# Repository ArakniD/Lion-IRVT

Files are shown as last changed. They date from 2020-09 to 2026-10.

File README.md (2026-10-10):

# Lion-IRVT

An eight-channel bidirectional battery test system (BTS) — charge and discharge,
constant-current and constant-voltage — for testing and characterising
18650-class lithium cells. The workspace file is `18650-Tester-Project.DsnWrk`;
that is what the instrument is for.

The power stage and control card derive from Texas Instruments reference design
**TIDA-010086**, a 10 A battery formation and test design that TI documents as
scalable to eight channels. Here it is built out to all eight, retargeted to the
**TMS320F28379D**, and split across both of its cores. An ESP32 sits on top as
host controller.

| Layer | Device | Job |
|---|---|---|
| Control | F28379D **CPU1** | Eight independent synchronous bidirectional converters. HRPWM, DCL control loops, external SPI ADC (ADS131M08), on-chip ADC, trip handling. |
| Communication | F28379D **CPU2** | I2C target register file for the host, I2C controller for F-RAM and the ADS1119 temperature converters, UART AT console (debug build), CAN telemetry, calibration and slot-state persistence. |
| Supervision | **ESP32** (LOLIN32 v1.0.0) | I2C controller. Owns the test sequence and cell limits, integrates mAh/mWh, records results, drives the eight WS2812B slot LEDs, and exposes BLE GATT, a JSON HTTP API with a setup page, WiFi firmware update, and an ST7789 LCD with a rotary encoder. |

## Configuring the unit — MODE and ENABLE switches

Two 8-way DIP switches on the board set how the unit runs. **MODE** decides
how the eight slots are grouped; **ENABLE** decides how many slots are in
use. Both are read **once, at power-on** — change a switch, then power-cycle.
**Turn on exactly one switch on each.** DIP *n* selects setting *n* − 1.

**MODE — slot grouping**

| MODE DIP | `eSlotMode` | Name | Slot groups | Voltage loop from | What it is for |
|---|---|---|---|---|---|
| **1** | **0** | Independent | 8 groups of 1 | ADS131M08 | **Normal use.** Eight separate cells, each with its own test |
| 2 | 1 | Pairs | 1+2, 3+4, 5+6, 7+8 | ADS131M08 | One cell on two slots in parallel, up to twice the current |
| 3 | 2 | Quads | 1–4, 5–8 | ADS131M08 | One cell on four slots, up to four times the current |
| 4 *(or none)* | 3 | Octet | 1–8 | ADS131M08 | One cell on all eight slots |
| 5 | 4 | Independent, internal ADC | 8 groups of 1 | C2000 12-bit ADC | As MODE DIP 1, with the voltage loop closed on the on-chip ADC |
| 6 | 5 | Pairs, internal ADC | as MODE DIP 2 | C2000 12-bit ADC | As MODE DIP 2, internal ADC |
| 7 | 6 | Loop tuning — plant | one slot | — | Bench only. SFRA sweep of the converter with its loop open |
| 8 | 7 | Loop tuning — closed loop | one slot | — | Bench only. SFRA sweep of the closed current loop |

In a group the slots are wired in parallel onto one cell. **Command the lowest
slot in the group only** — the others follow it. The group's current limit is
the **total**, shared across its slots; voltage limits apply as written.

**ENABLE — slots in use**

| ENABLE DIP | `eSlotEnable` | Slots enabled | Slots off |
|---|---|---|---|
| 1 | 0 | 1 | 2–8 |
| 2 | 1 | 1–2 | 3–8 |
| 3 | 2 | 1–3 | 4–8 |
| 4 *(or none)* | 3 | 1–4 | 5–8 |
| 5 | 4 | 1–5 | 6–8 |
| 6 | 5 | 1–6 | 7–8 |
| 7 | 6 | 1–7 | 8 |
| **8** | **7** | **all eight** | — |

**Typical settings**

| To run | MODE DIP | ENABLE DIP |
|---|---|---|
| Eight cells, one per slot | 1 | 8 |
| One cell on slot 1 only (bench bring-up) | 1 | 1 |
| Four cells, two slots each | 2 | 8 |
| Two cells, four slots each | 3 | 8 |
| One cell on all eight slots | 4 | 8 |

> **No switch on reads as DIP 4**, which is MODE 3 / ENABLE 3: one group of
> eight with only slots 1–4 enabled — a combination that cannot run. Always
> set both straps. And **the straps must agree**: a group that ENABLE cuts
> short has its hardware over-current trips disabled. Pairs need an even
> number of slots enabled; quads, four or eight; the octet, all eight.

Check what the unit actually latched in `slot_mode` and `slots_enabled`
(`GET /api/status`), or `AT+SMD?` / `AT+SEN?` on the ESP32's console, rather
than trusting the switch positions. Every detail — group semantics, the
loop-tuning modes, the switch wiring and decode — is in
[`hardware-resources.md` §11](Hardware/source/Docs/hardware-resources.md#11-mode-and-enable-straps).

## Status — 2026-10-08

What has run on hardware, as opposed to what compiles. One slot - slot 1 -
has been exercised; the other seven run the same firmware but have not been
driven yet.

| | |
|---|---|
| **Standalone boot** | Both cores boot from flash with the debugger unplugged; CPU1 starts CPU2 and confirms that CPU2's boot ROM took the command |
| **Charge** | 1 A into a short: 205 s, regulated at 1.00 A, 57.0 mAh, no trip |
| **Discharge** | 1 A from a 3.46 V supply: 206 s, 57.7 mAh. 100 mA: steady. No trip on enable |
| **Discharge termination** | `V_MIN` 0.5 V, supply wound down to 0 V: the slot ended in END (`FINISHED`), not as a trip |
| **F-RAM** | Calibration, slot state and the global thresholds load at boot with 0 read failures, and save with 0 failures |
| **Temperatures** | All eight slots read live from both ADS1119s |
| **ESP32** | BLE GATT, the setup page, saving WiFi credentials, and over-the-air update with rollback - verified on a bare ESP32 |
| **Home Assistant** | Installs from HACS; the HACS validator and hassfest pass on GitHub |

**Not yet verified on hardware:** charge termination and the CV loop (the
charge test ran into a short, which never leaves constant current); the
±9.5 A hardware trip *level* against a real over-current; slots 2–8 under
load; and an over-the-air update confirming itself on a live BTS link rather
than through its 180 s fallback. Details:
[`Docs/supervision-and-state-design.md`](Hardware/source/Docs/supervision-and-state-design.md)
§2.6 and [`Docs/README.md`](Hardware/source/Docs/README.md).

The current ESP32 firmware talks BLE and HTTP directly. **Home Assistant
support is now a custom component**, in its own repository
[ha-lion-irvt](https://github.com/ArakniD/ha-lion-irvt) and checked out here as
the submodule `Hardware/source/lion-lvrt-integration/`. It speaks BLE, HTTP or
CAN from the HA side — the tester itself carries no
MQTT or native-API client, and does not need one. The superseded ESPHome
`esp32-controller/` variant was the only firmware that ever reported to HA
directly.

```mermaid
flowchart TB
    subgraph CARD ["controlCARD — TMS320F28379D"]
        direction LR
        C1["<b>CPU1</b> — control<br/>8 × bidirectional converters<br/>HRPWM · DCL loops<br/>ADS131M08 over SPI<br/>on-chip ADC · trips<br/>slot + calibration state machines"]
        C2["<b>CPU2</b> — comms<br/>I2CA target 0x50<br/>I2CB: F-RAM + 2× ADS1119<br/>AT console · CAN<br/>persistence · watchdog"]
        C1 <-->|"message RAM<br/>single-writer"| C2
    end

    POWER["Power stage × 8<br/>TIDA-010086 derived<br/>sense resistors · NTCs"]
    FRAM["FM24V10 F-RAM<br/>calibration + slot state"]

    subgraph PROXY ["ESP32 — LOLIN32 v1.0.0"]
        LINK["bts_link — I2C master"]
        ENG["test engine<br/>owns the sequence"]
        UI["ST7789 LCD + rotary encoder<br/>8× WS2812B slot LEDs"]
    end

    HA["Home Assistant<br/>lion_lvrt component"]
    CLI["calibrate.py<br/>bench automation"]
    WEB["Browser / curl"]
    TERM["Bench terminal<br/>debug build only"]

    POWER <--> C1
    C2 <-->|"I2CB 100 kHz"| FRAM
    C2 <-->|"I2CA 50 kHz<br/>big-endian floats"| LINK
    LINK <--> ENG
    ENG --> UI

    ENG <-->|"BLE GATT<br/>little-endian"| HA
    ENG <-->|"BLE"| CLI
    ENG <-->|"HTTP JSON :80"| WEB
    ENG <-->|"HTTP"| HA
    C2 <-->|"CAN 500 kbit/s"| HA
    C2 <-->|"SCIA 115200"| TERM
```

The two C2000 cores share data through the message RAMs under a single-writer
rule: **CPU1 never writes the register file.** It publishes measurements into
`cpu1Status` under a seqlock and CPU2 mirrors them into `registers[]`. Every
data-flow decision in the firmware follows from that — including supervision:
CPU2 detects a watchdog timeout and reads the saved slot state at boot, but
**CPU1 performs every state change**, because CPU1 owns the control loop.

[`Docs/data-flow.md`](Hardware/source/Docs/data-flow.md) draws all of this —
the measurement path from shunt to phone, the command path back, calibration,
settings persistence and what each transport can actually control.

### Unattended-operation safety

The instrument charges lithium cells unattended, so three coupled mechanisms
decide what happens when something stops going right:

- **A 30 s host watchdog.** Any host command on any interface reloads it —
  including an I2C register *read*, which is what a polling host actually
  does. If nothing talks to the unit for 30 seconds, every running slot
  pauses with the converter off. It is a supervision timeout measured in
  seconds, **not** over-current protection.
- **A PAUSED slot state.** A paused slot keeps its direction and its six
  per-direction counters — mAh, mWh and elapsed seconds for each of charge and
  discharge — frozen but intact, and resumes exactly where it stopped. The
  status word says *why* it is paused, which is what decides whether resuming
  is safe.
- **F-RAM state persistence.** Each slot's run state and counters are saved
  every 6 s and restored at boot. A slot that was mid-run when the unit reset
  comes back **paused, with its counters, and refuses to resume on its own** —
  the cell may have been changed while the unit was off. That rule is
  deliberate and hardware-verified; do not script around it.

---

## Repository layout

| Path | Contents |
|---|---|
| `Design/` | Pre-layout analysis, not build inputs: TINA-TI simulations (`.TSC`) of the current loop and the synchronous buck, the inductor/LC selection spreadsheet, and vendor app notes. |
| `Hardware/schematics/` | Altium projects. `TIDA-010086/` is the modified TI reference design, `TIDA-010086_exTrip/` the added external trip logic, `Lion-IRVT/` the front-end and cell-holder sheets, `controlCARD/` the F28379D controlCARD reference. |
| `Hardware/mechanical/` | DXF/DWG for the 4-wire 18650 slot jig and the enclosure, plus laser-cut sheet layouts. |
| `Hardware/publish/` | A generated output set from Feb 2021 — Gerbers, drills, BOM, pick-and-place, assembly drawings, 3D/STEP. A snapshot, not regenerated on every change. |
| `Hardware/source/` | **All firmware.** See below. |
| `References/` | Component libraries, footprints, vendor 3D models and datasheets. **Entirely gitignored** (`References/*`) — the directory exists locally but nothing in it is tracked. Expect it to be empty on a fresh clone. |

Inside `Hardware/source/`:

| Path | Contents |
|---|---|
| `tida-010086/bts_F2837xD_8ch/` | The C2000 dual-core firmware. This is the instrument. |
| `esp32-btle-proxy/` | **Current** ESP32 host firmware (ESP-IDF). |
| `esp32-controller/` | Superseded ESPHome-based controller (2025), which reported to Home Assistant. |
| `esp32-bridge/` | Superseded Arduino WiFi bridge (2024). |
| `lion-lvrt-integration/` | **Home Assistant custom component** — a git **submodule**, [ha-lion-irvt](https://github.com/ArakniD/ha-lion-irvt). Plus a firmware-accurate simulator and its pytest suite. Speaks BLE, HTTP or CAN. |
| `Docs/` | The authoritative interface and calibration specifications. Start here. |
| `references/` | Datasheets and manuals used while writing the firmware: F2837xD TRM, controlCARD guide, ADS131M08, ADS1119, the LOLIN32 schematic, and the XTIDA-010086E3 schematic PDF. |
| `.claude/` | Agent skills and project notes. |

### Documents

`Hardware/source/Docs/` is source-verified and is the thing to read before the
code:

| File | What it is |
|---|---|
| [`README.md`](Hardware/source/Docs/README.md) | Operator bench procedure for slot calibration. Wiring, safety, step by step, troubleshooting. |
| [`api-specification.md`](Hardware/source/Docs/api-specification.md) | Part 1 the HTTP API; Part 2 the complete I2C register map — **280 registers in four regions** — with the transaction shapes, the supervision watchdog and the slot-state persistence contract. **The authority for any register address.** |
| [`ble-specification.md`](Hardware/source/Docs/ble-specification.md) | The full GATT service: 12 characteristics, packed layouts, notify behaviour, protocol versioning. |
| [`data-flow.md`](Hardware/source/Docs/data-flow.md) | **New.** How measurements, commands, settings and calibration move between CPU1, CPU2, the ESP32 and a host — as diagrams. Includes the dead measurement paths and the traps in the IPC decode. |
| [`supervision-and-state-design.md`](Hardware/source/Docs/supervision-and-state-design.md) | The design contract for the PAUSED state, the host watchdog and F-RAM state persistence. |
| [`calibration-design.md`](Hardware/source/Docs/calibration-design.md) | The calibration mathematics, opcodes, state machine and F-RAM layout. A design document: its addresses track the v2.1 map, but where the two disagree **`api-specification.md` §2.8 is the authority**. |
| [`calibration-flow.md`](Hardware/source/Docs/calibration-flow.md) | The calibration procedure and state machine as Mermaid flow, state and sequence diagrams. |
| [`hardware-resources.md`](Hardware/source/Docs/hardware-resources.md) | PIE vectors, ACK groups, XINT, X-BAR and ADC base allocation across both cores, and the two I2C buses (§10). The authority for interrupt resources and bus speeds. |

---

## The three ESP32 projects — build the right one

There are three, and only one is live.

| Directory | Added | Toolchain | Status |
|---|---|---|---|
| `esp32-bridge/` | Aug 2024 | Arduino `.ino` | **Superseded.** A WiFi/OSC bridge over a packet-oriented I2C protocol that predates the float register map. |
| `esp32-controller/` | Apr 2025 | ESPHome YAML + C++ components | **Superseded.** Built on ESPHome, so it surfaced the unit to **Home Assistant** as sensors, switches and selects - the only variant that ever did. Adds a HID barcode scanner and a `bts_i2c` component. Its I2C layer is wrong in two ways: `bytes_to_float()` assembles the float in host order under a comment asserting "BTS uses little-endian float", when the wire format is big-endian; and `read_register()` requests four bytes where five are needed, so it never discards the lead-in pad byte. Do not copy from it. |
| `esp32-btle-proxy/` | Sep 2026 | ESP-IDF v6.1 | **Current.** Everything else in this README refers to this one. |

The two superseded trees are retained for the pin assignments and the
barcode-scanner work, not as a starting point.

---

## Building

Clone with the submodule, or the Home Assistant integration directory is
empty:

```bash
git clone --recurse-submodules https://github.com/ArakniD/Lion-IRVT.git
# or, in an existing clone:
git submodule update --init
```

### C2000 firmware

TI Code Composer Studio, installed here at `C:/ti/ccs2101`. The dependency is
the **C2000Ware Digital Power SDK** (`C:/ti/c2000/C2000Ware_DigitalPower_SDK_5_03_00_00`)
for driverlib, DCL, the SFO HRPWM calibration library and SFRA.

Open the project `bts_F2837xD_8ch` from
`Hardware/source/tida-010086/bts_F2837xD_8ch`. It has **two build
configurations, `cpu1` and `cpu2`, and both must be built** — they compile the
same sources with `--define=CPU1` or `--define=CPU2` and link against different
`.cmd` files, producing `bts_F2837xD_8ch_cpu1.out` and `..._cpu2.out`.

- `cpu1` is the active configuration; CCS's own build tooling handles it, and
  inside CCS that is the only supported way to build it.
- `cpu2` is built from its generated `cpu2/makefile`, which the CCS build
  produced and which carries the full `--define=CPU2` command line.

After building, check the `.map` files. Every shared symbol must land at the
same address in both, and `CPU2TOCPU1RAM` must not overflow. There are
**eight** shared symbols: `registers`, `ipcMsg`, `calValidFlags`,
`supervision`, `canData`, `cpu1Status`, `startup_mode` and `startup_enable`.

The current tree builds clean on both cores, all eight symbols resolve
identically in the two map files, and `CPU2TOCPU1RAM` has **304 words free of
1024** (`0x2D0` used). `CPU1TOCPU2RAM` has 516 free.

> **Both cores now have their own complete flash bank, and this was wrong
> before.** On the F2837xD each CPU has its *own* full bank, both mapped at the
> same addresses — 0x080000–0x0BFFFF is CPU1's flash when CPU1 fetches it and
> CPU2's when CPU2 does. Proved on hardware: 0x090000 returns real code on CPU1
> and `0xFFFF` on CPU2. The project previously split one bank between the cores
> (CPU1 = A–I, CPU2 = J–N) with CPU2's `codestart` at 0x0B0000, which wasted
> most of each core's flash and left **CPU2's boot-to-flash entry at 0x080000
> erased** — a standalone boot would have sent CPU2's boot ROM into an illegal
> opcode. Both linkers now name the full bank with `BEGIN` at 0x080000, as TI's
> reference linkers do.

> **Do not run code from a GSx RAM block on one core while the other can be
> flashed.** CCS programs flash by staging its algorithm in target RAM, and for
> a CPU2 `loadProgram` it stages in **RAMGS0**. The GSx blocks are shared
> silicon, so that overwrote CPU1's `ramfuncs` and dropped CPU1 into the
> illegal-operation handler the instant CPU2 was loaded — before CPU2 executed
> a single instruction. CPU1's ramfuncs now run from RAMLS0, which is per-core.
> Load order is no longer significant and both cores run together.

> **Loading both cores.** Starting a debug session loads only the active
> configuration (`cpu1`). CPU2 is left running whatever was in its memory, and
> because CPU2 owns I2CA, a CPU1-only reload leaves the ESP32 link dead while
> CPU1 looks perfectly healthy. Worse, the console and every clock-derived
> divisor on CPU2 stay built for the *previous* clock configuration — which is
> what produced the long-running "the AT console is at the wrong baud rate"
> false trail. **Rebuild and reload both cores after any clock change.**

Both configurations define `_FLASH` and boot from flash. The clock is a 20 MHz
crystal, ×18 /2 = **180 MHz SYSCLK**, LSPCLK 45 MHz; measured on hardware at
179.7 MHz by `BTS_HAL_getMeasuredSysclkKHz()`, which counts SYSCLK against
INTOSC1 on a timer pair rather than trusting a register read. Prefer it to any
JTAG register read or baud-rate inference — `ClkCfgRegs` reads all-zero on this
part while the core is running, and every earlier clock estimate that came
through the console baud rate shared a single confound.

### ESP32 firmware

ESP-IDF **v6.1**, target `esp32`, on the LOLIN32 v1.0.0 (ESP-WROOM-32, 4 MB).

**The stock `export.ps1` does not work on this machine.** It resolves `python`
from `PATH` and finds the system Anaconda 3.6 interpreter before the IDF venv.
`idf_env.ps1` sets the same variables directly, taken from the paths the
editor's ESP-IDF extension is configured with, and additionally sets
`ESP_IDF_VERSION`, which `idf_component_manager` reads unconditionally and
crashes on `None` if it is unset.

```powershell
cd Hardware\source\esp32-btle-proxy
. .\idf_env.ps1
idf.py build
idf.py -p COM6 flash monitor
```

Configuration lives in `sdkconfig.defaults`; regenerate `sdkconfig` from it
rather than hand-editing. The partition table is custom (`partitions.csv`):
dual OTA slots plus a second NVS partition for the result history, so filling
it with test records cannot displace the WiFi credentials or chemistry
overrides.

> This board has no auto-program circuit that works reliably. If `esptool`
> reports `Wrong boot mode detected (0x13)`, use the BOOT button, or see
> `tools/enter_download.py`.

**After the first USB flash, update over WiFi.** Upload
`build/bts_btle_proxy.bin` from the setup page at `http://<tester>/`, or post
it to `/api/ota` with `curl --data-binary` and an `X-OTA-Key` header. The new
image is on trial until the BTS link answers a register poll, and rolls back
by itself if it is rebooted before then. The **first** flash of any board
must be a full USB flash, because rollback lives in the bootloader. See the
[ESP32 README](Hardware/source/esp32-btle-proxy/README.md#firmware-update-over-wifi).

---

## Tools

`Hardware/source/esp32-btle-proxy/tools/`.

> **Python on this machine:** the system `python` is **3.6** and too old for
> every script here. Use the IDF venv interpreter:
> `C:\Espressif\tools\python\v6.1\venv\Scripts\python.exe` (3.11).

### Bench automation

| Script | |
|---|---|
| **`calibrate.py`** | The significant one. Guided two-point slot calibration, walking slots 1–8 and prompting at each connection change. Drives the tester over **BLE** (`bleak`) and an Agilent/Keysight **DMM over LAN SCPI on TCP 5025** as the traceable reference. Refuses to advance until the live per-unit reading is inside the required window, prints a before/after gain table, and writes a JSON report. Config is prompted once and persisted to `calibrate.ini`. Flags: `--slots 3,5` or `--slots 2-4`, `--dry-run` (full flow against a simulated tester and DMM, **no hardware needed**), `--reconfigure`, `--report`, `--allow-unknown-dmm`. Every exit path — normal, Ctrl-C, or an unhandled exception — issues `CAL_CMD_EXIT`, so a slot is never left driving current. |

### BLE bring-up

| Script | |
|---|---|
| `ble_scan.py` | Scan and dump anything that looks like the tester. Confirms it is advertising before you try to connect. |
| `ble_verify.py` | Connect and verify the whole GATT interface against the packed structs in `ble_proto.h`, subscribing to both notify characteristics. Non-zero exit on failure, so it works as a bench smoke test. |

### Serial and flashing

These exist because the LOLIN32's reset circuit cannot reliably self-enter
download mode on this host. They are a diagnostic chain, roughly in the order
they were written, and each one's docstring records what the previous
established.

| Script | |
|---|---|
| `probe_reset.py` | Determines which DTR/RTS combination drives EN and IO0, by reading the ROM's own `boot:0x..` banner rather than guessing polarity. |
| `probe_io0.py` | Given that RTS drives EN, tests whether DTR reaches IO0 at all. |
| `probe_dtr_alone.py` | Characterises DTR on its own. |
| `sweep_reset.py` | Sweeps the EN-release / IO0-assert timing gap looking for a window that works. |
| `enter_download.py` | The result: drives DTR/RTS directly to enter download mode, after which `idf.py -p COM6 --before no-reset flash`. |
| `try_download_hard.py` | Last-resort strategies, each verified by a real esptool SYNC. |

### Code generation

| Script | |
|---|---|
| `gen_font.py` | Generates `components/display/ui_font.c`, the 5×7 UI font table. The output is committed; re-run only if the glyph set changes. |

---

## Interfaces

Five host interfaces. Register tables are **not** duplicated here — the
specifications are authoritative.

> **Endianness differs by interface and this is the detail most likely to cost
> you an afternoon.** The I2C register wire format is **big-endian** (the
> C2000's `floatGetWireByte()` emits the float MSB first). The BLE records are
> **little-endian**. HTTP carries JSON numbers, so no byte order applies. The
> conversion happens in `bts_regs.h`; nothing above `bts_link` sees the C2000's
> byte order.

| Interface | Where | Authority |
|---|---|---|
| **I2C register map** | C2000 CPU2 as target at `0x50` on I2CA (GPIO32/33); the ESP32 is master. **280 float registers in four regions** — runtime (base 0, stride 48 B, read-only), settings (base 384, stride 72 B), unit (960–1064) and slot tuning (1068–1116, the DCL biquad coefficients, one set for the whole unit). The map tops out at **1116**, not at the end of the unit block. The two per-slot strides **differ** — always derive through the base macros. A slot's live data is one 12-register burst, which is why a poll cycle costs 9 transactions rather than the 33 it used to. A read must fetch `1 + count×4` bytes and **discard the first**: the target clocks out a stale byte before its ISR can run. The bus runs at **50 kHz** — see [Hardware notes](#hardware-notes). | [`api-specification.md`](Hardware/source/Docs/api-specification.md) Part 2 |
| **BLE GATT** | ESP32, NimBLE. One primary service `e5f10001-…`, **12 characteristics**, advertised as `BTS-Tester`. The 128-bit service UUID is in the **scan response**, not the advertising payload, because it will not fit alongside the name. `BLE_PROTO_VERSION` (currently **7**) is published so a client can refuse a firmware it cannot decode. The interface is **append-only**, so a newer firmware only adds characteristics and appends fields: v4 added the register-access characteristic `000d`, which is what lets a BLE client reach the C2000 mode register at all, and v7 appended the pre-charge balance flags to the slot record. Disconnecting does **not** abort running tests. | [`ble-specification.md`](Hardware/source/Docs/ble-specification.md) |
| **HTTP API** | ESP32, port 80, JSON, **no authentication and no encryption**, except a key on firmware upload. A setup page at `/` (live unit state, WiFi credentials, firmware update), unit and per-slot status, slot config and control, result history, the cell catalogue, raw register access for bring-up, and the calibration endpoints. WiFi comes up APSTA: saved station credentials are joined if present and the `BTS-Tester` SoftAP stays up either way. | [`api-specification.md`](Hardware/source/Docs/api-specification.md) Part 1 |
| **UART AT console** | C2000 CPU2, SCIA on the controlCARD FTDI backchannel, **115200 8N1**. `AT+<name>?` and `AT+<name>=<value>` against short or long register names, plus `AT+C<n>PAUSE` / `AT+C<n>RESUME`. **Only available in the debug build** (`BTS_DEBUG_CONSOLE == true`; it is `false` today). The production build leaves GPIO28/29 idle — the WS2812B string that used to share GPIO29 is driven by the ESP32 now. The ESP32 runs an AT console of its own on its USB port, which proxies the same commands to the unit. A bare `AT` is ignored by design — probe with `AT+InputVoltage?`. | `.claude/skills/bts-c2000-interfaces-skill/references/uart-at-commands.md` |
| **CAN** | C2000 CPU2, CANA, 500 kbit/s, extended IDs from `0x1C000000`. Message objects 1–8 are per-channel telemetry; object 9 is a host register read/write. The telemetry frame carries voltage in full but **only the low word of the current float**, and no accumulators — read those through object 9. | [`data-flow.md`](Hardware/source/Docs/data-flow.md) §7 |

Data flow across all five, including what each one can actually control, is in
[`Docs/data-flow.md`](Hardware/source/Docs/data-flow.md).

---

## Hardware notes

### The two I2C buses

Both buses have only **10 kΩ pull-ups** on the board, and that decides their
speed. The rise time of an RC pull-up is about 0.85 × R × C: with 10 k that is
424 ns at an optimistic 50 pF and 847 ns at 100 pF. **Fast mode (400 kHz)
allows 300 ns**, so at 400 kHz both buses are out of spec at any real
capacitance. **Standard mode (100 kHz) allows 1000 ns**, which 10 k meets up to
about 118 pF. Running faster needs ~2.2 kΩ pull-ups — and nothing here needs
the bandwidth.

| | Host bus (I2CA) | Peripheral bus (I2CB) |
|---|---|---|
| **C2000 pins** | GPIO32 SDA, GPIO33 SCL — target | GPIO40 SDA, GPIO41 SCL — controller |
| **Devices** | the C2000 at **0x50** | FM24V10 F-RAM **0x50**, ADS1119 **0x40** (slots 1–4) and **0x41** (slots 5–8) |
| **Clocked by** | the ESP32 (GPIO21 SDA, GPIO22 SCL) | the C2000 |
| **Speed** | **50 kHz** | **100 kHz** |
| **Why that speed** | Runs over a ribbon to the ESP32, and the C2000's target ISR does real work per byte | The pull-ups — see above |
| **Pull-ups** | 10 k on the board, plus the ESP32's internal pull-ups | 10 k on the board |

**I2CB was at 400 kHz until 2026-10-08.** It produced about 327 F-RAM save
failures and roughly one ADS1119 bus stall a second; at 100 kHz both are 0.
The poll bounds in `com_cpu2.c` were raised 4× at the same time, so a slower
but healthy transfer cannot trip them (`BTS_I2C_TIMEOUT_ITERATIONS`). The
longest transfer on the bus — a 162-byte calibration record — takes ~15 ms and
happens once, at boot.

**Neither bus can be faster than it is without a hardware change.** If the
pull-ups are ever reduced, the full reasoning and the measurements are in
[`hardware-resources.md` §10](Hardware/source/Docs/hardware-resources.md#10-i2c-buses).

What protects each bus from a stuck transfer:

- **I2CB** — every transfer records who started it, which device, how far it
  got and how it ended. The first failure is frozen in `i2cbFaultSnap`, and
  `i2cbHist[]` holds the last 16. A held bus is freed by clocking SCL nine
  times (the standard recovery) and resetting the module. `i2cbFramBusy`
  keeps the F-RAM and the ADS1119s from interleaving.
- **I2CA** — the C2000 resets its target if the bus sits busy with no address
  match for too long (`serviceI2CTargetWatchdog()`). The ESP32 resets its own
  controller after any failed transfer.
- **Never halt CPU2 in the debugger mid-transfer.** It leaves the host bus
  wedged with SCL held low, and the recovery runs on the core you halted.

### Boot

- **SW1 off = boot from flash** (the boot-mode switch on the controlCARD).
  When programming, load CPU1 first, then CPU2: loading CPU1 resets CPU2.
- **A cold power-up with the XDS100 attached will not boot.** A powered probe
  holds TRSTn high, so the boot ROM takes the emulation path and ignores SW1.
  Unplug the probe for a standalone boot.
- CPU1 starts CPU2 itself and waits a bounded time for CPU2's boot ROM to
  acknowledge, resending the command if it does not. CPU1's control tasks,
  supervision and trip arming run even if CPU2 never comes up.

### Straps

MODE and ENABLE are DIP switches read once at power-on, through an SN74HC148
priority encoder. **DIP switch *n* selects setting *n* − 1**: DIP 1 is 0, DIP 8
is 7. Turn on **one switch at a time** — with more than one on, the encoder
reports only one of them.

**All switches off reads the same as DIP 4, which is setting 3.** The encoder
outputs the same code for "no switch on" as for its input 0, which is where
DIP 4 is wired, and the board does not bring out the GS pin that would tell
them apart. So an unstrapped board comes up in MODE 3 (one group of eight)
with ENABLE 3 (slots 1–4) — a part-populated group that cannot run a test.
Always set both straps.

| DIP switch on | 1 | 2 | 3 | 4 or none | 5 | 6 | 7 | 8 |
|---|---|---|---|---|---|---|---|---|
| **Setting** | 0 | 1 | 2 | 3 | 4 | 5 | 6 | 7 |

The switches are not wired to the encoder in order — DIP 1–4 reach its inputs
3–0, DIP 5–8 its inputs 4–7 — and `truth_table[]` in `bts_hal.c` maps them
back. The full derivation is in [`hardware-resources.md` §11](Hardware/source/Docs/hardware-resources.md#11-mode-and-enable-straps).
Check a setting against what the unit reports (`slot_mode` and
`slots_enabled` in `GET /api/status`, or `AT+SMD?` and `AT+SEN?` on the
ESP32's console) rather than trusting the switch position.

What each setting does is in
[Configuring the unit](#configuring-the-unit--mode-and-enable-switches), at
the top of this file.

### Which comparator watches which slot

Each slot's hardware over-current trip (±9.5 A) is a CMPSS comparator on the
pin its current-sense net reaches. The device fixes each comparator's pins and
the board routes the sense nets for layout, so **slot *n* is not `CMPSSn`**:

| Slot | Current sense | Device pin | Comparator | Voltage sense | Device pin |
|---|---|---|---|---|---|
| 1 | `IoutS1` | `ADCINA2` | **CMPSS1** | `VoutS1` | `ADCINA3` |
| 2 | `IoutS2` | `ADCINB2` | **CMPSS3** | `VoutS2` | `ADCINB3` |
| 3 | `IoutS3` | `ADCINA4` | **CMPSS2** | `VoutS3` | `ADCINA5` |
| 4 | `IoutS4` | `ADCIN14` | **CMPSS4** | `VoutS4` | `ADCIN15` |
| 5 | `IoutS5` | `ADCIND0` | **CMPSS7** | `VoutS5` | `ADCIND1` |
| 6 | `IoutS6` | `ADCINC2` | **CMPSS6** | `VoutS6` | `ADCINC3` |
| 7 | `IoutS7` | `ADCIND2` | **CMPSS8** | `VoutS7` | `ADCIND3` |
| 8 | `IoutS8` | `ADCINC4` | **CMPSS5** | `VoutS8` | `ADCINC5` |

The voltage pin is the same comparator's negative input and is not used by
it: both comparators compare against their internal DAC. The binding is
`BTS_TRP_CMPSS_CH1..8` in `bts_user_settings.h`. The full table, with each
net's 0-ohm link, `J5` pin, comparator input and ADC SOC, is in
[`hardware-resources.md` §5.0](Hardware/source/Docs/hardware-resources.md#50-which-comparator-watches-which-slot).

---

## Calibration

Each slot's measurement error is calibrated out against a **traceable external
reference** — your DMM — at two points per quantity, replacing what used to be
compile-time constants in `bts_user_calibration.h` with per-slot runtime values
persisted to the on-board FM24V10 F-RAM and reloaded at every boot.

Both measurement paths are calibrated from the same physical stimulus at the
same instant: the 16-bit ADS131M08 and the 12-bit on-chip ADC. They therefore
agree with each other as well as with the meter.

Read [`Docs/README.md`](Hardware/source/Docs/README.md) before running it —
that is the operator procedure. The sequence and state machine are drawn in
[`Docs/calibration-flow.md`](Hardware/source/Docs/calibration-flow.md), where
the data goes in [`Docs/data-flow.md`](Hardware/source/Docs/data-flow.md) §5,
and the mathematics in
[`Docs/calibration-design.md`](Hardware/source/Docs/calibration-design.md)
(a design document — where it and the API specification disagree on an
address, **the API specification wins**).

Two things belong here rather than only in the procedure:

> ### Hardware over-current protection is disabled in this build
>
> All eight hardware trips are `(false)` in `bts_user_settings.h:113-120`. The
> only over-current protection left is a software check that runs once per
> control pass — fast enough for a gradual overload, **not** fast enough for a
> genuine short. Calibration deliberately drives about 2.5 A.
>
> **Do not run calibration unattended, and set the bench supply's own current
> limit (3 A) before you start.** The supply's limit is your fast protection,
> because the unit's is not armed.

> **Enter the DMM current as a magnitude.** Calibration runs in discharge and
> the firmware applies the sign itself. Entering `-2.4991` where `2.4991` was
> wanted inverts that slot's current reading — it will look plausible, pass
> validation, and be wrong on every subsequent discharge.

---

## Home Assistant

The integration lives in its own repository,
[ha-lion-irvt](https://github.com/ArakniD/ha-lion-irvt), so it can be installed
through HACS without the firmware. It is checked out here as the submodule
`Hardware/source/lion-lvrt-integration/`, at the same path as before, so its
test suite finds the firmware's C headers beside it and checks every wire
layout against them.

To change it: commit inside the submodule and push to ha-lion-irvt, then commit
the new submodule pointer here.

It is a custom component: eight slot
devices plus a unit device, with mode selects, start/stop/pause/resume buttons,
measurements, status binary sensors, configuration numbers and the BTS's own
per-direction counters. Services cover slot configuration, serial assignment,
mode, resume, calibration commands and result retrieval.

Copy `custom_components/lion_lvrt/` into your HA `config/custom_components/`
and restart, or add the repository to HACS. The tester advertises as
`BTS-Tester`, so HA discovers it automatically if a **connectable** Bluetooth
adapter or proxy is in range.

> **Choose the transport deliberately — it decides which controls appear.**
> There are two separate control surfaces. The **test engine** on the ESP32
> runs a whole characterisation and picks the direction itself; the **mode
> register** on the C2000 commands the converter directly. "Test this cell" is
> the first, "charge this slot" the second, and they are reached differently:
>
> | Transport | Test engine | Charge / discharge |
> |---|:---:|:---:|
> | Bluetooth | yes | only on `BLE_PROTO_VERSION` ≥ 4 |
> | HTTP | yes | yes |
> | CAN | no | yes |
>
> The register characteristic that makes charge and discharge reachable over
> BLE arrived in proto 4. Against older proxy firmware the integration hides
> those modes rather than offering an action that would fail — add the CAN
> interface or the HTTP address during setup (either one is enough) to get them
> back.

The `tests/` directory carries a firmware-accurate simulator and a pytest
suite, so the component can be exercised without hardware. Note that a dry run
cannot catch a **struct-layout** mismatch: the Python `struct` formats must be
verified against `ble_proto.h` by hand whenever the BLE records change.

---

## TODO and known limitations

Verified against the source, not aspirational. Split by whether it is a
decision or a gap.

### By design — do not "fix" these without reading why

- **The ESP32 owns the test sequence, not the BTS.** The C2000 regulates;
  termination, capacity integration, cell limits and state are the proxy's job.
  Two of the gaps below follow from this rather than being defects.
- **The C2000 terminates; the ESP32 decides what a test is.** The build is
  CC-CV (`BTS_LAB_TYPE = BTS_LAB_CLOSED_LOOP_CCCV`). A slot ends itself in
  END: a discharge when the ADS131M08 reads at or below `V_MIN`, a charge
  only once the CV loop holds `V_MAX` and the current has tapered to `I_MIN`.
  Either condition must hold for 5 consecutive passes of the C1 task — about
  0.17 s at the 28.6 Hz measured on 2026-10-02 — and a group leader ends its
  whole group. `V_MIN = 0` disables the discharge
  check. The ESP32 engine still sequences charge, rest and discharge around
  that.
- **Calibration telemetry is unit-scoped, not per-slot.** Only one slot
  calibrates at a time; eight copies of the nine-register window would cost 144
  words of message RAM and buy nothing.
- **The ESP32 keeps its own coulomb counting even though the BTS now has
  accumulators.** `coulomb_counter.c` integrates against the actual elapsed
  time between polls, which is finer than the BTS's fixed 150 ms step, so it
  stays the reported figure. The BTS totals are read alongside it for
  comparison.
- **A restored slot is never auto-resumed.** After a reset, a slot that was
  running comes back `PAUSED` + `RESTORED` and waits for an explicit command,
  because the cell may have been swapped while the unit was off. Neither the
  firmware nor the proxy will resume it for you. This is the single most
  safety-critical rule in the supervision work.
- **CPU2 detects the watchdog timeout but does not act on it.** It bumps a
  counter in the `supervision` mailbox and CPU1 performs the pause. The
  single-writer rule covers control state, not just memory.
- **The F-RAM and the ADS1119s are serialised on I2CB, and deliberately so.**
  They share the bus with incompatible access styles — a non-blocking converter
  state machine that leaves a transfer in flight across service calls, and
  blocking F-RAM helpers that complete inside one. `i2cbFramBusy` grants the
  F-RAM the bus only while **both** converters are parked in `eAdsIdle` or
  `eAdsSettle`, and a save that cannot acquire stays pending and retries rather
  than being dropped. Removing the flag reproduces the original failure: both
  frames corrupted and the controller left holding SCL with nothing running to
  free it.
- **The per-slot limits live with the run state, not in the calibration
  image.** Calibration is measured once against a traceable reference;
  operating limits change whenever someone adjusts a charge current. Keeping
  them together meant rewriting the calibration block on every settings change.
- **Thermistor AIN indices are inverted to slots in firmware.** The hardware is
  wired `AIN3 → slot 1` on both converters. `ADS1119_SLOT_FOR_AIN()` corrects
  it at the publish call, so a console `ChN` is a **slot**, not an AIN.

### Resolved since the last revision

| | |
|---|---|
| ~~Nothing asserts end-of-test; no current-taper termination~~ | **Fixed, and discharge termination verified on hardware.** The CC-CV build drives END in both directions (above). Slot 1 discharging at 1 A with `V_MIN` 0.5 V ended in END when its supply was wound to 0 V. Charge termination is implemented but **not yet run** — the charge test was into a short, which never reaches CV. |
| ~~All hardware over-current trips are disabled~~ | **Enabled, and the path proven end to end.** All eight CMPSS comparators trip at ±9.5 A, reach the trip zones through the Digital Compare submodule, and arm on a slot's first run rather than at boot. They latched on every discharge enable while the deadband took its two delays from different sources (`DBCTL` IN_MODE 2); with both from EPWMA, no run since has tripped. The **level** has not been tested against a real over-current. |
| ~~The unit never boots without the debugger~~ | **Fixed.** `_STANDALONE` is defined beside `_FLASH`, so CPU1 starts CPU2, with a bounded wait and a resend if CPU2's boot ROM does not acknowledge. A cold power-up with the XDS100 **attached** still cannot boot: a powered probe holds TRSTn high and the boot ROM ignores the boot switch. Unplug it. |
| ~~F-RAM reads fail at every boot~~ | **Fixed.** A stop bit left armed in `I2CMDR` by an earlier transfer rode into the read's address phase, so calibration and slot state silently fell back to defaults on every boot. `I2CMDR` is now written outright, and boot reads retry up to 8 times. 0 read failures since. |
| ~~Temperatures read 0.00 °C after a cold boot~~ | **Fixed.** A lost DRDY edge left the ADS1119 state machine idle forever. A converter quiet for 1 s is now read anyway, and one disabled after repeated failures is re-armed after 10 s. This also retires the old "the ADS1119 state machine stalls after a JTAG load" entry. |
| ~~The over-current indication never clears~~ | **Fixed 2026-10-09** (build only, no hardware yet). `eTripStatus` and status bit 3 clear when the slot is handed back — clearing the fault on the ESP32 (it sends the unit a new clear-fault mode command, `0x40`), a fresh start, a `WAITING` re-arm, or removing the cell. Deliberately **not** on a stop: the ESP32 sends a stop as its first reaction to a trip, and clearing there would wipe the fault before anyone saw it. |
| ~~The comparator that trips a slot watched a different slot's current, on slots 2, 3, 5, 7 and 8~~ | **Fixed 2026-10-09, and the routing read back from the board.** Each comparator's input pins are fixed by the device, and the board routes each slot's sense nets for layout, so slot *n* is not watched by `CMPSSn`: slot 2 is `CMPSS3`, slot 3 `CMPSS2`, slot 5 `CMPSS7`, slot 7 `CMPSS8` and slot 8 `CMPSS5`. The firmware assumed `CMPSSn`, so slots 2 and 3 tripped on each other's current and 5, 7 and 8 in a ring — in the ungrouped and pair modes; quads and the octet were unaffected. Each slot is now bound to the comparator on its own current pin (`BTS_TRP_CMPSS_CH1..8`), and on the board slot 2's trip now reads `CMPSS3`. No trip has been forced. See [Which comparator watches which slot](#which-comparator-watches-which-slot). |
| ~~The MODE and ENABLE straps read 0 after a power cycle, whatever the switches said~~ | **Fixed 2026-10-09, and verified on the board.** The decode table was an initialised array, and this project links with `--ram_model`, so only a debugger load ever wrote it: after a standalone boot from flash it held zeros, and every switch position decoded to MODE 0 / ENABLE 0. It is `const` now, in flash. The table itself was also corrected against the schematic, so each DIP switch selects the setting printed beside it (see [Straps](#straps)). The value reaches the ESP32 correctly: the unit latched MODE 3 / ENABLE 2 and `AT+SMD?` / `AT+SEN?` returned the same. |
| ~~The slot temperatures stall~~ | **Fixed 2026-10-10, and verified on the board.** About 1.5 % of I2CB frames to the ADS1119s timed out: a new frame was started the moment the bus went free, before the module had cleared the previous frame's stop bit, and the start was lost. Each loss counted as a converter failure and was retried, so readings arrived late and in bursts, and a converter could go quiet for seconds. Every frame now waits for the stop to finish completely. On the board: 4523 good frames to 1 timeout, no converter failures. See [`hardware-resources.md` §10.6](Hardware/source/Docs/hardware-resources.md#106-a-new-frame-must-wait-for-stp-not-just-for-the-bus). |
| ~~The GPIO trip inputs were configured on every slot~~ | **Fixed 2026-10-09.** They are not fitted on this board, and now have their own switches, `BTS_TRIP_GPIO_CH1..8_ENABLED`, all `false`. Until then the pin setup and X-BAR routing were gated on the CMPSS switches, so enabling the comparators also configured seven unwired inputs and put channel 6's on `INPUT14`, which slots 5–8 need. Only the CMPSS comparators trip now. |
| ~~The ESP32 panics when the BTS stops answering~~ | **Fixed.** A failed `i2c_master_probe()` in ESP-IDF v6.1 leaves a dangling operation list behind, and the next transfer crashed on it. The proxy no longer scans the bus while the link is down, and resets the bus after any failed transfer. |
| ~~A spurious `WARNING: host watchdog DISABLED` on the AT console~~ | **Gone.** The warning and its flag were removed on 2026-09-22 (`8070d2e`); nothing prints it any more. |
| ~~The AT console's baud rate is wrong, and the cause is unknown~~ | **Resolved — the console works at 115200.** It was never a hardware fault. The console is served by **CPU2**, whose `SCI_setConfig()` derives BRR from `DEVICE_LSPCLK_FREQ`; the clock config was edited repeatedly with only CPU1 rebuilt, so CPU2 kept a divisor built for the previous clock and the apparent baud moved every time. Every "independent" clock measurement came through that same console and shared the confound. SYSCLK measures **179.7 MHz** against a configured 180 MHz. A bare `AT` producing no reply is separate and **by design** — `uartRxISR()` matches only `"AT+"`. |
| ~~SYSCLK is running at 10 MHz, not 160~~ | **Never true.** Same confound as above. `BTS_HAL_getMeasuredSysclkKHz()` now measures the clock on-core against INTOSC1, and `BTS_HAL_setupDevice()` halts on a result outside ±5 %. A real defect was found on the way: `SysCtl_setClock()` returns false on a latched MCD **having touched no PLL register**, and `device.c` discarded the return value — a genuine silent 10 MHz failure mode with perfect-looking registers. MCD is now cleared before `Device_init()` and the return checked. |
| ~~The flash layout splits one bank between the cores~~ | **Fixed.** Each core's linker now names its own complete bank with `BEGIN` at 0x080000, as TI's reference linkers do. CPU2's boot-to-flash entry is no longer erased. |
| ~~A CPU2 load traps CPU1 in the illegal-operation handler~~ | **Fixed.** CCS stages its flash algorithm in **RAMGS0**, which is shared silicon, and it was overwriting CPU1's `ramfuncs`. CPU1's ramfuncs now run from RAMLS0, which is per-core. Load order is no longer significant. |
| ~~The ADS1119 temperature readings land on the wrong slot~~ | **Fixed.** The thermistors are wired in reverse on both converters — the highest AIN carries the lowest slot. `ADS1119_SLOT_FOR_AIN()` inverts the index at the publish call. Verified with a thermistor taped to the ESP32: it moved from `Ch3` to `Ch0`. |
| ~~Every F-RAM access fails while the converters read fine~~ | **Fixed.** The F-RAM and both ADS1119s share I2CB with incompatible access styles — a non-blocking converter state machine that leaves a transfer in flight, and blocking F-RAM helpers. The frames interleaved, both corrupted, and the controller was left holding SCL. `i2cbFramBusy` serialises them; a save that cannot acquire stays pending and retries rather than being lost. Verified: a global threshold survives a full CPU2 restart, and bus recoveries stayed at 0 through repeated 8-channel calibration writes. |
| ~~`INT_ADCB1` faults CPU1 into the unhandled-interrupt handler~~ | **Fixed** in `bts_hal.c`. |
| ~~The trip zones all trip EPWM1~~ | **Fixed.** |
| ~~The ESP32 mirror is one register short~~ | **Fixed** 2026-09-20, and brought across again with the 2026-09-22 settings compression. Both headers now agree on 280 registers, a 960 unit base, the 1032–1064 telemetry window and a top address of 1116. There is still **no build coupling**, so it can drift again. |
| ~~The mAh/mWh accumulators are never written~~ | **Live.** Six counters per slot — mAh, mWh and elapsed seconds for each direction — integrated on CPU1, contiguous in the runtime block, and **persisted to F-RAM across a reset**. Each direction's set is zeroed only when that direction starts. |
| ~~The per-run min/max voltage trackers are never written~~ | **Deleted from the map.** They were RO and never assigned — 16 registers of permanent 0.0. |
| ~~The BTS never signals end-of-test~~ | **Bit 2 is now driven.** `BTS_STATUS_END` is an alias for `BTS_STATUS_FINISHED` (bit 2) rather than a new bit. Cleared on start, pause and stop, and **restored from F-RAM at boot**. Wired end to end — but see below for what still does not assert it. |
| ~~There is no supervision timeout anywhere in the firmware~~ | **Closed.** A 30 s host watchdog, reloaded by any command on any interface including an I2C read, pauses every running slot if the host goes quiet. |

### Not yet implemented

| | |
|---|---|
| **The ENABLE strap does not read ENABLE DIP 8.** | With ENABLE DIP 8 on (2026-10-09), the encoder lines read `A2 A1 A0` = `1 1 0`, the code for DIP 3, where DIP 8 is `0 0 0`; the unit therefore runs slots 1–3. None of the three lines is pulled low, and A0 (GPIO57) is floating. A hardware fault between the switch and the C2000, not the firmware — check U26's supply and EI, its pins 9/7/6, and `J5` pins 15/13/11 across R276/R283/R281. See `Docs/hardware-resources.md` §11. |
| **Channel 6's trip input is under bench investigation.** | Suspected of not being properly connected (2026-10-09). Channel 6 has one trip input on this board: comparator CMPSS6, whose positive input `CMPIN6P` is `ADCINC2` — the same pin the firmware samples as slot 6's current, on the schematic's `IoutS6` net (0-ohm link R253, `J5` pin 90). The GPIO trip inputs are not fitted, so nothing else can trip it. Slot 6's comparator was already right, so the comparator fix above does not change it. See `Docs/hardware-resources.md` §4. |
| **The internal-ADC current reads ~60 mA high at low current.** | Slot 1 at a 100 mA setpoint: ADS131M08 0.10 A, internal ADC 0.16 A; they agree to 2 % at 1 A. A zero offset that the two-point calibration will remove. The control loop and the counters use the ADS131M08, so regulation is unaffected. |
| **A calibration commit does not mark a slot calibrated.** | `eCalibrationMode = 2` saves the current gains to F-RAM but keeps whatever validity flags the slot already had, so committing a slot's factory gains still leaves its calibration ticks (`CAL_V_VALID`/`CAL_I_VALID`) clear. The runtime calibration's `CAL_CMD_COMPUTE_SAVE` sets them. |
| **The global voltage thresholds persist only through a calibration commit.** | `eChargeDisableV` … `eDischargeDisableV` (960–972) take effect when written, but are saved to F-RAM only by `eCalibrationMode = 2`. Write them, then commit, or they revert at the next boot. |
| **The ESP32's AT console can repeat its last reply.** | Seen once on 2026-10-08: about 17,000 copies of one reply to a single command, with the proxy otherwise healthy. Not yet investigated. It does not affect the C2000, but it will confuse any tool parsing the ESP32's console. |
| **A cell temperature of 18.32 °C is not a measurement.** | `BTS_NTC_POLY_C0` is 18.323 and the Horner evaluation returns exactly C0 for a zero input, so 18.32–18.90 °C means an **open input** — an empty slot. Measured 2026-10-10 with only slot 1's thermistor fitted: slots 2–7 read 18.89 °C (an ADS1119 code of about 260) and slot 8 reads 18.32 °C (code 0). |
| **`bts_regs.h` is a hand-maintained mirror of `registers.h` with no build coupling.** | Adding a register means editing both, and they have drifted twice. Worse, the two files use the **same identifiers for different things**: `BTS_STATUS_*` and `BTS_CAL_ST_*` are bit *positions* on the C2000 and bit *masks* on the ESP32; the `BTS_RT_*`, `BTS_SET_*` and `BTS_CAL_*` offsets are register *indices* on one side and *byte* offsets on the other; and `BTS_RT_BASE` / `BTS_SET_BASE` are function-like macros returning an index on the C2000 and bare byte-address constants on the ESP32. `BTS_RT_STATUS` is `0` in both files, while `BTS_RT_CELL_VOLTAGE` is `1` on the C2000 and `4` on the ESP32. Copying a line between the files compiles and is wrong. |
| **There is no spare register left in any region.** | The 2026-09-22 compression spent the settings region's slack. A new per-slot field now means another stride change, which moves every address below it and breaks every host — the thing the generous strides were chosen to avoid. `CPU2TOCPU1RAM` is no longer the binding constraint (304 of 1024 words free); the map layout is. |
| **Every slot must be recalibrated, and the saved state was invalidated too.** | Both F-RAM headers were bumped: the calibration image `0xA5CC` → `0xA5CD` for the `calFlags`/`crc32` revision and the fixed 128-byte stride, and the slot-state record `0x5A5E` → `0x5A5F` for the 64-byte layout. The calibration change also fixed a collision in which channel 4's block overwrote the global voltage thresholds — which consequently had *never* persisted. The state change fixed a 20-word record running 8 bytes into the next slot's header, so that only slot 7 could ever validate. |
| **The C2000 and the ESP32 must be flashed together.** | The 2026-09-22 compression moved every settings and unit address. A mismatched pair reads plausible-looking garbage rather than failing loudly, because every address in this map is a valid float somewhere else in it. |
| **No mDNS.** | Nothing in the firmware registers a `.local` name. Use the IP address the device logs on connect (`idf.py monitor`). |

---

## Working on this codebase

`Hardware/source/CLAUDE.md` holds the agent guidelines — most importantly, that
`C:/ti/ccs2101/ccs/theia/resources/ai/CCS.md` must be read before touching any
CCS tooling, and that CCS projects are built through the project MCP server
rather than by invoking `gmake` directly.

`Hardware/source/.claude/skills/bts-c2000-interfaces-skill/` is the system
overview and the interface authority for the C2000 side: the IPC contract and
core responsibilities, the I2C specification, the UART AT command set and the
calibration EEPROM process. `.claude/README.md` alongside it is a
feature-by-feature summary of what the firmware implements.

Rules the whole firmware design rests on, and that are easy to break:

- **Never insert a register mid-map.** External hosts hard-code byte addresses.
  **There is no spare register left in any region** — the 2026-09-22 settings
  compression spent the slack — so any new field now means a stride change,
  which moves every address below it. Update the `registers.h` enum, the
  `NUM_*` counts, `TOTAL_REGISTERS`, `regConfig[]` and `uartRegConfig[]`
  **together** (the tables are sized by `TOTAL_REGISTERS` and must stay
  index-aligned), plus the ESP32 `bts_regs.h` mirror, which has no build
  coupling and has drifted twice.
- **The two per-slot regions have different strides**, 12 registers and 18.
  Always index through `BTS_RT_BASE(ch)` / `BTS_SET_BASE(ch)`. Mixing them
  produces silent cross-channel corruption rather than an error.
- **CPU1 does not decode every register it is sent.** `BTS_HandleRegisterWrite()`
  handles the settings region's mode register and calibration group, plus
  `eCalCommand`. Anything else — including `eCalibrationMode` and
  `eHostWatchdog_s` — has its IPC flag acked and is silently discarded, so a
  new register needs an explicit entry or it will be accepted by CPU2 and
  quietly ignored by CPU1. The decode is **by index range**, so it has to be
  re-derived every time the map moves.
- **Rebuild and reload both cores after any clock or register-map change.**
  Each core is a separate binary and CPU2 keeps whatever divisors and addresses
  it was last built with. A CPU1-only reload leaves a plausible-looking system
  that is lying to you — this is what produced the long "the console is at the
  wrong baud rate" and "SYSCLK is at 10 MHz" false trails, both of which came
  through a stale CPU2 binary.
- **Do not run code from a GSx RAM block on one core while the other can be
  flashed.** CCS stages its flash programming algorithm in target RAM, and for
  a CPU2 load it stages in RAMGS0 — shared silicon. LS blocks are per-core; GS
  blocks are not.
- **Do not halt CPU2 in the debugger mid-I2C-transaction.** The recovery for a
  wedged I2C target runs from CPU2's own idle loop, so stopping that core part
  way through a transfer leaves the target holding SCL with nothing running to
  clear it. The ESP32 link does not come back without a reload or a power
  cycle. A debugging artefact rather than a firmware fault, but it costs a
  bring-up session every time.
- **Do not judge a peripheral from a JTAG session alone.** Register reads over
  JTAG are stale and differ per core view — `ClkCfgRegs` reads all-zero on this
  part while the core is running, and the ADS1119 state machine stalls after a
  `loadProgram` in a way a flash boot never shows. Prove a path is live with a
  sentinel value and the AT console instead.

---

## Licence and provenance

Licensed under the **GNU General Public License v3** — see [`LICENSE`](LICENSE).

The power stage, control card and the original firmware derive from TI
reference design **TIDA-010086**, whose own firmware descends from the TI
`TIDM-DC-DC-BUCK` PowerSUITE example. TI's notice and disclaimer is retained
in `Hardware/schematics/TIDA-010086/`. The build-out to eight channels, the
split across both cores, the host interfaces and the runtime calibration are
this project's.

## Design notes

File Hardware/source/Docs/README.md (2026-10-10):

# Slot Calibration — Bench Procedure

How to calibrate one or more slots on the eight-channel battery test system
(BTS), with the hardware in front of you.

This is the operator's document. You do not need to read anything else to run
a calibration.

### The other documents in this directory

| File | What it is |
|---|---|
| [`api-specification.md`](api-specification.md) | Part 1 the HTTP API; Part 2 the **complete I2C register map** — 280 registers in four regions, verified against `registers.h`. The authority for any address |
| [`ble-specification.md`](ble-specification.md) | The GATT service: 12 characteristics, packed record layouts, notify behaviour, protocol versioning |
| [`data-flow.md`](data-flow.md) | How measurements, commands, settings and calibration move between CPU1, CPU2, the ESP32 and a host. Diagrams, the measured rates, the CLA telemetry filter, and the dead paths |
| [`supervision-and-state-design.md`](supervision-and-state-design.md) | The design contract for the PAUSED state, the host watchdog and F-RAM state persistence |
| [`calibration-design.md`](calibration-design.md) | The calibration mathematics, opcodes and state machine. A design document — for any address, `api-specification.md` §2.8 is the authority |
| [`calibration-flow.md`](calibration-flow.md) | The calibration procedure and state machine as diagrams |
| [`hardware-resources.md`](hardware-resources.md) | PIE, ACK groups, XINT, X-BAR, ADC base and CLA1 allocation across both cores |
| [`esp32-hardware-connections.md`](esp32-hardware-connections.md) | ESP32 proxy pin usage: the ST7789 LCD, rotary encoder, WS2812B slot LEDs and I2C link, by header pin and GPIO |

---

## Read this first

> ### Hardware status, 2026-10-08 - converter verified, trip levels not
>
> Slot 1 has now run real current both ways on this firmware, and ended on its
> own termination rule. Measured on the bench:
>
> | Test | Result |
> |---|---|
> | Charge, 1 A into a short | ran 205 s, regulated at 1.00 A, no trip |
> | Discharge, 1 A into a 3.46 V supply | ran 206 s, 57.7 mAh, no trip on enable |
> | Discharge, 100 mA | ran until stopped, no trip on enable |
> | Discharge termination, `V_MIN` 0.5 V | supply wound to 0 V; slot ended as **END** (`FINISHED`), not as a trip |
>
> The two current paths agree at 1 A (ADS131M08 1.00 A, internal ADC 0.98 A),
> and the charge counter integrates to the commanded current (57.0 mAh in
> 205 s at 1 A). Before this, a discharge latched the CMPSS low comparator on
> every enable; the deadband input fix and the converter duty seed cleared it.
>
> **What is still unproven is the trip LEVEL**, which is why the section below
> stands. The comparators have now been seen to latch - wrongly, on the old
> deadband - but never against a real over-current at the ±9.5 A threshold.
>
> **Two things that look like faults and are not:**
>
> - **A discharge that stops after a few seconds with no fault bit** is the
>   input-bus guard. The energy a discharge removes goes back onto the input;
>   a supply that cannot sink it rises toward `eDischargeRestrictV`, and the
>   slot is stopped there. Raise the limits (now 16.0 / 16.8 V, and 16.8 V is
>   the firmware ceiling) or give the input a load.
> - **A discharge that ends at once as `FINISHED`** is the `V_MIN` cutoff, not
>   a trip. A bench supply in current limit collapses the slot voltage the
>   moment the converter starts drawing; give it more current headroom.
>
> **The internal-ADC current reads ~60 mA high at low current** (0.16 A
> against the ADS131M08's 0.10 A at a 100 mA setpoint), while agreeing to 2%
> at 1 A - a fixed zero offset, uncorrected because the slot has not been
> through the two-point routine. The control loop and the counters use the
> ADS131M08, so regulation is unaffected; anything reading `eChX_CellCurrent`
> at low current is not.

> ### The hardware over-current trips have not been tested at their level
>
> All eight are **enabled** in this build (`BTS_TRIP_HW_CH1..8_ENABLED (true)`,
> [`bts_user_settings.h`](../tida-010086/bts_F2837xD_8ch/bts_user_settings.h)),
> and they are **armed only while a slot is running** — `serviceTripArming()`
> in `bts_cpu1.c` arms the comparators once a slot is commanded to run and
> disarms when the last one stops. Arming at boot is not possible: an unpowered
> sense chain reads as −10 A and would latch a trip on every slot before the
> board did anything.
>
> So a calibrating slot is covered from the moment it starts driving current —
> with one exception worth knowing: a group is **all-or-nothing**. If the
> ENABLE strap masks off any member of the group you are calibrating, the whole
> group is left unrouted and none of it has a hardware trip, even while
> running. In an ungrouped build (MODE 0) each slot is its own group and the
> exception does not arise.
>
> The caution is therefore not "there is no trip". It is this: **the trips are
> live and have been seen to latch, but never against a real over-current.**
> The levels (±9.5 A hardware, above the 8 A software trip) have not been
> measured, so treat the supply's own limit as the protection you trust.
>
> Three consequences, all of which matter during calibration because
> calibration deliberately drives real current:
>
> 1. **Do not run calibration unattended.** Stay at the bench with a hand near
>    the supply's output switch.
> 2. **Set the bench supply's own current limit before you start.** 3 A is a
>    sensible backstop for the 2.5 A the procedure draws. Treat it as your
>    fast protection until the unit's own trip has been seen to work.
> 3. **An untested trip can fail the other way too.** If a sense chain does not
>    behave as documented, a slot may latch a trip the instant it starts rather
>    than failing quietly. A slot that trips immediately on every start is this,
>    not a wiring fault at the terminals.

> ### Enter the DMM current as a MAGNITUDE
>
> Calibration runs in **discharge**, and the firmware applies the discharge
> sign itself. When the meter reads `-2.4991 A`, you enter `2.4991`.
>
> Entering `-2.4991` is the single easiest way to end up with an inverted
> current reading on that slot — it will look plausible, pass validation, and
> report every subsequent discharge with the wrong sign. `calibrate.py` takes
> the absolute value for you; if you are driving the sequence by hand over
> HTTP, this is on you.

---

## What calibration does, and why

Each slot has two independent measurement paths looking at the same cell:

| Path | Converter | Resolution | Used for |
|---|---|---|---|
| External | ADS131M08 | 16-bit | the control loop's current reference, and reporting |
| Internal | F2837xD on-chip ADC | 12-bit at a 2.5 V reference | the cell voltage and current a host reads today |

Neither is accurate out of the box. Component tolerance in the sense
resistors, the divider networks and the converter references means each slot
reads a few percent off, and differently from its neighbours.

Calibration measures that error against a **traceable external reference** —
your DMM — at two points per quantity, fits a straight line through them, and
stores the resulting gain and offset for that slot. Both paths are calibrated
at the same time, from the same physical stimulus, so they agree with each
other as well as with the meter.

The results live in the FM24V10 F-RAM on the unit and are reloaded at every
boot. They survive a power cycle. (The function names in the firmware say
`readEEPROM` / `writeEEPROM`, but the part is F-RAM — there is no write-cycle
budget to worry about and no erase delay.)

**A slot needs calibrating when:** it is a new or repaired unit, a sense
resistor or converter has been replaced, the slot disagrees with a meter by
more than about 1 %, or the firmware's calibration header revision has changed
(after which every slot falls back to compiled defaults and reports no ticks).

---

## Equipment

| | |
|---|---|
| **DC bench supply** | 0–5 V, 3 A, with an adjustable current limit and a genuine constant-current mode. This is both the voltage source for the voltage phase and the current sink path for the current phase. |
| **DMM** | Agilent/Keysight with a LAN port, SCPI on TCP 5025. Verified models: 34401A, 34410A, 34411A, 34450A, 34460A, 34461A, 34465A, 34470A. It must measure DC volts and DC amps to at least 2.5 A. |
| **Host** | A PC with Python 3.10+, `bleak` installed, on the same network as the DMM and in Bluetooth range of the tester. |
| **Leads** | Two pairs of test leads for the slot terminals, plus a set for the DMM. Use leads rated for 3 A on the current path — thin probe leads drop enough voltage at 2.5 A to matter. |
| **The tester** | Powered from its DC input, advertising over BLE as `BTS-Tester`. |

You do **not** need a cell in the slot. Calibration uses the external supply
for both phases. Remove any cell before you start.

---

## Bench preconditions

These two will waste an afternoon if you skip them.

**1. The DC input must be above `eChargeDisableV` (default 9 V).**

Below it, the unit settles into `eInputLow_ChargeDisabled` and **no slot will
start** — the guard is checked both when a mode is written and again at 10 Hz
while running, so a marginal input stops a slot a fraction of a second after
it starts, which looks like an intermittent fault rather than a supply
problem. Check the reported input voltage before you begin:

```
curl http://<tester-ip>/api/status | grep input_voltage
```

Note this is the guard on the **input bus**, not the cell voltage on the slot.

**2. A latched `TZOSTFLG` cannot be cleared while its trip source is still
asserted.**

If a slot tripped earlier, clearing the fault does nothing until you remove
whatever is asserting the trip. A clear that "doesn't take" is this, not a
dead slot. Fix the cause, then clear.

**3. Slots may come back from a reset as `PAUSED` + `RESTORED`.**

The unit saves each slot's run state to F-RAM every 6 s. If it was power-cycled
or reset while a slot was running, that slot comes back **paused, with its
counters intact, and deliberately refuses to resume on its own** — the cell
may have been swapped while the unit was off.

Calibration is refused while any slot is running a test, and a restored slot
still counts as running for that check. `/api/status` shows it as
`bts.restored: true`. Stop it (`POST /api/abort_all`) before you calibrate;
resuming it is the wrong move if you are about to pull the cell out anyway.

**4. The host watchdog will pause running slots after 30 s of silence.**

If nothing is polling the unit — no ESP32, no script — every slot that is
charging or discharging pauses after 30 seconds, with `bts.watchdog_tripped`
set. This does **not** affect the slot you are calibrating: a calibrating slot
is not "running" in that sense and the watchdog leaves it alone. It affects
any *other* slot that happened to be mid-test, which is another reason to stop
everything before a calibration session.

`calibrate.py` drives the unit over BLE, and each of its commands becomes an
I2C write through the proxy, so the traffic does reach the watchdog. But the
thing that keeps it fed reliably is the proxy's own 250 ms I2C poll — **leave
the ESP32 powered and connected** for the whole session.

That same poll is what lights the slot LEDs. The proxy owns the strip, so
unplugging the ESP32 mid-session does not just stop the watchdog being fed —
it stops the indicators telling you anything. See the troubleshooting table.

---

## Wiring

Calibration has two phases and they need different connections. The script
prompts you at each change; this is what those prompts mean.

### Voltage phase — DMM in PARALLEL

The supply sets the slot terminal voltage; the DMM measures what is really
there.

```
    DC bench supply                    BTS slot N
    +-------------+                  +-----------+
    |          (+)|------------+-----| (+)       |
    |             |            |     |           |
    |          (-)|------+-----|-----| (-)       |
    +-------------+      |     |     +-----------+
                         |     |
                       (-)|   |(+)
                      +---------+
                      |   DMM   |   CONF:VOLT:DC
                      +---------+
```

Connect the DMM **at the slot terminals**, not at the supply. The lead
resistance between them is exactly the error you are trying to calibrate out.

Supply output ON, current limit 0.5 A is plenty for this phase.

### Current phase — DMM in SERIES

The slot draws a fixed discharge current; the supply is the sink path for it,
and the DMM counts every amp on the way through.

```
    DC bench supply                    BTS slot N
    +-------------+                  +-----------+
    |          (+)|---+          +---| (+)       |
    |             |   |          |   |           |
    |             | +---------+  |   |           |
    |             | |   DMM   |--+   |           |
    |             | +---------+      |           |
    |             |   |  CONF:CURR:DC|           |
    |             |   +--------------+           |
    |          (-)|---------------------| (-)    |
    +-------------+                  +-----------+
```

Move the DMM's lead from the volts jack to the **amps jack** — on most
Keysight meters that is a physically different terminal, and forgetting is the
usual cause of a reading of zero.

Set the supply to about 3.7 V and **set its current limit to 3 A**. That limit
is the safety backstop for the whole procedure.

---

## Procedure

### The automated way

```powershell
cd esp32-btle-proxy
py -3.10 tools\calibrate.py
```

On the first run it asks for the DMM's IP address, the SCPI port (5025) and
the tester's BLE address (leave blank to scan for `BTS-Tester`). Those are
saved to `tools\calibrate.ini` and reused.

The script then walks slots 1 to 8, prompting at each connection change and
refusing to advance until the slot's live reading is inside the required
window. Useful flags:

| Flag | Effect |
|---|---|
| `--slots 3,5` | only those slots; `--slots 2-4` also works |
| `--dry-run` | the whole flow against a simulated tester and DMM, no hardware |
| `--reconfigure` | re-prompt for the addresses |
| `--report out.json` | where the JSON report goes |

At any prompt, `s` skips the current slot; Ctrl-C stops the run. Both paths
issue `CAL_CMD_EXIT`, so a slot is never left driving current.

### What happens per slot

1. **Connect** — supply and DMM across the slot, DMM in parallel.
2. **Enter calibration** — the slot stops regulating and zeroes its reference,
   but keeps measuring. Its LED flashes white.
3. **Voltage, low point** — set the supply to about **0.85 V**. Wait for the
   live per-unit reading to settle below 0.2. The DMM reading is captured.
4. **Voltage, high point** — raise the supply to about **4.25 V**, per-unit
   above 0.8. Captured.
5. **Current, zero point** — supply output off, current path broken. The slot
   captures what it reads with no current flowing. This is the offset.
6. **Current, loaded point** — DMM into series, supply to 3.7 V with its limit
   at 3 A, output on. The slot drives 0.25 pu of discharge (about 2.5 A) and
   settles for two seconds. The DMM reading is captured as a magnitude.
7. **Compute and save** — the two-point fit runs, the results are validated
   against their expected windows, written to F-RAM and reloaded into the
   control core.
8. **Exit** — the reference is zeroed and the slot returns to normal.
9. **Verify** — the script reads the slot's status bits back and confirms both
   ticks are set.

> **Why 0.85 V and 4.25 V, when the design document's worked example says 1.0 V
> and 4.0 V?** At the gain these slots actually have, 1.0 V reads 0.2024
> per-unit — just *above* the `< 0.2` low window, so the capture is rejected.
> 4.0 V clears the high window by only 1.5 %. The values here leave margin at
> both ends. If your slot's gain differs, follow the live per-unit number the
> script prints rather than the voltage.

### Doing it by hand

Every step is an HTTP POST, if you would rather drive it yourself. Full
request and response shapes are in
[`api-specification.md`](api-specification.md).

```bash
T=http://<tester-ip>
curl -X POST $T/api/calibration/enter         -d '{"slot":2}'
curl -X POST $T/api/calibration/voltage       -d '{"measured_v":0.84968}'
curl -X POST $T/api/calibration/voltage       -d '{"measured_v":4.24992}'
curl -X POST $T/api/calibration/zero_current  -d '{}'
curl -X POST $T/api/calibration/fixed_current -d '{"pu":0.25}'
sleep 2
curl -X POST $T/api/calibration/current       -d '{"measured_a":2.4991}'   # MAGNITUDE
curl -X POST $T/api/calibration/save          -d '{}'
curl -X POST $T/api/calibration/exit          -d '{"slot":2}'
curl     $T/api/calibration
```

`slot` is **0-based** on the wire (slot 3 on the front panel is `{"slot":2}`).
The script shows you 1-based numbers and converts.

---

## Reading the display

While a slot is calibrating, the panel switches to the calibration screen and
shows only that slot:

```
+--------------------------------+
| CALIBRATION      SLOT 3        |
+--------------------------------+
|           ADS131    F28 ADC    |
|  V        4.1982    4.1975  [v]|
|  pu       0.8412    0.8409     |
|  A       -2.4991   -2.4987  [v]|
|  pu      -0.2502   -0.2499     |
|  T        23.4 C               |
+--------------------------------+
| LO set  HI set   I0 set        |
+--------------------------------+
```

- **Two number columns.** `ADS131` is the 16-bit external converter, `F28 ADC`
  the 12-bit internal one. They should agree to roughly the resolution of the
  12-bit path — around 1 mV on voltage. A large disagreement after a
  successful calibration means one path's wiring is not what you think.
- **`pu` rows** are the raw per-unit readings the two-point maths consumes,
  before any gain is applied. These are the numbers the capture windows
  (< 0.2, > 0.8) are checked against.
- **The green ticks `[v]`** at the right of the V and A rows are the point of
  the whole exercise. A tick means that slot has valid, persisted calibration
  for that quantity. They are driven from what is stored in F-RAM, not from
  this session's captures, so **a slot calibrated last month still shows its
  ticks today**. A slot with no tick is running on compiled defaults.
- **The footer** lists which capture points are currently held: `LO set`,
  `HI set`, `I0 set`, `I1 set`. They clear when you exit or clear.
- **The slot's LED flashes white** while it is calibrating. A fault colour
  out-ranks it — if the LED shows a trip, the trip is what matters.
- **The LEDs come from the ESP32 proxy, not from the unit.** The proxy reads
  each slot's state over its 250 ms I2C poll and drives the strip itself, so a
  colour can lag the slot it describes by up to about a quarter of a second.
  It also means the strip has two failure modes of its own — all eight amber,
  and frozen — both in the troubleshooting table below.

The encoder does nothing during calibration. Press and long-press only write
to the log; the procedure is driven over BLE or HTTP.

---

## Troubleshooting

| What you see | What it means | What to do |
|---|---|---|
| `per-unit reading outside the required window` | The supply is set so the slot reads between 0.2 and 0.8 pu — the firmware cannot tell which point you meant. | Follow the live pu number the script prints. Below 0.2 for the low point, above 0.8 for the high. Roughly 0.85 V and 4.25 V. |
| `busy - another slot is already in calibration` | Only one slot calibrates at a time. | `CAL_CMD_EXIT` the other slot. `CAL_CMD_ENTER` force-exits the others, so this usually means a stale session from a crashed script. |
| `slot is running a test - stop it first` | A charge or discharge test is active somewhere on the unit. **A slot that came back `PAUSED` + `RESTORED` after a reset counts as running.** | Stop it: `POST /api/abort_all`. |
| `slot is disabled by its ENABLE strap, or is a group follower` | The ENABLE dip switch masks this slot off, or it follows a lower-numbered leader and has no control loop of its own. | Check the MODE/ENABLE straps. In a group, calibrate the leader. |
| `insufficient captures` | Voltage needs both points; current needs the zero plus one loaded point. | Capture the missing point. Save computes and stores whichever of the two is complete, so a partial result is normal, not a failure. |
| `computed gain failed validation` | The fit landed outside its expected window — `IoutGain_pu` outside 0.05–0.20, or `VoutGain_pu` outside 0.10–0.40. | Almost always a wiring error: DMM on the wrong terminals, in the wrong jack, or measuring a different slot. Check and redo. |
| `F-RAM write failed` | The I2C write to the FM24V10 did not complete. | Check the I2C bus: `GET /api/i2c_diag`. |
| The slot never starts; nothing happens | The input bus is below `eChargeDisableV` and the unit is in `eInputLow_ChargeDisabled`. | Bring the DC input above 9 V. Check `/api/status`. |
| The slot stops about half a second after starting | Same cause. The input guard runs again at 10 Hz. | As above. |
| The slot trips during the current phase | Real over-current, or a trip source still asserted. Calibration exits and zeroes the reference — as designed. | Check the wiring for a short. A latched `TZOSTFLG` will not clear while its source is asserted. |
| Nothing happens for two minutes, then the slot stops | The dead-man timeout. If no calibration command arrives for 120 s while a slot is driving current, it auto-exits. | Expected. Re-enter and continue. |
| DMM reads 0 A in the current phase | The lead is in the volts jack. | Move it to the amps jack. |
| Another slot paused itself partway through the session | The host watchdog. Nothing talked to the unit for 30 s, so every *running* slot paused. The slot under calibration is unaffected. | Expected. Check the ESP32 is powered and its I2C link is up (`GET /api/i2c_diag`), then resume or stop the slot. |
| A slot shows `restored` after you power-cycled the unit | The F-RAM state block. It was mid-run when the unit went down, and came back paused with its counters rather than resuming into a cell that may have been changed. | Working as designed. Stop it before calibrating; resume it only if you know the same cell is still in the slot. |
| All eight LEDs flashing amber together | The ESP32 proxy cannot reach the unit over I2C. The proxy itself is alive — it is still driving the strip — but it has nothing current to show. Amber is used for nothing else, so this is always the link, never a slot condition. | Check the I2C wiring between the proxy and the unit, and `GET /api/i2c_diag`. Everything the proxy reports — display, HTTP, BLE — is stale until it clears. |
| The LEDs are frozen on a colour and never change | The ESP32 is dead, unplugged or held in reset. It drives the strip, and a WS2812B holds its last colour indefinitely once the frames stop — so you are looking at whatever was true when the proxy stopped. **Do not trust them.** A slot showing green may have tripped since. | Confirm it: the display, HTTP and BLE all come from the same ESP32, so they will be gone too. Power-cycle the proxy, then read the slot state back before touching anything. |
| The AT console answers only garbage | **Build skew**, not a hardware fault. The console is served by **CPU2**, and `SCI_setConfig()` derives its divisor from `DEVICE_LSPCLK_FREQ`. Editing the clock config and rebuilding only CPU1 leaves CPU2's divisor built for the old clock. | Rebuild and reload **both** cores, then connect at **115200 8N1**. |
| The AT console says nothing at all to `AT` | **By design.** `uartRxISR()` matches only `"AT+"`; a bare `AT` is dropped with no `OK` and no `ERROR`. | Probe with a real command, e.g. `AT+InputVoltage?`. |
| Current reads the right size with the wrong sign afterwards | A signed value was entered where a magnitude was wanted. | Recalibrate that slot's current. Enter the absolute value. |
| `unsupported DMM` on connect | `*IDN?` returned a model the script does not know. | Check it is the right instrument. `--allow-unknown-dmm` overrides, if you are sure it speaks the same SCPI. |
| Both ticks stay grey after a successful save | The save reported bit 7 but the status bits did not follow. | Re-read `/api/calibration`. If it persists, the F-RAM image may have failed validation on reload — power-cycle and check. |

---

## After calibration

The script prints a before/after gain table per slot and writes a JSON report
(`calibration-report.json` by default). Keep it with the unit's records — it is
the evidence of what the slot measured against a traceable reference, on what
date.

Verify the result independently before you trust the unit:

1. Put a known voltage on the slot and confirm the reported voltage matches the
   DMM.
2. Confirm the external and internal paths agree to about the 12-bit path's
   resolution.
3. Power-cycle the unit and confirm the values and the green ticks survive.
4. Deliberately provoke an over-current during a calibration and confirm the
   slot still trips and exits. Do this once on a new unit — it is the check
   that the safety path is real, and as of this writing **no board has been
   seen to trip**, so on an early unit this is not a formality. Put a scope on
   the slot's PWM and start low.

---

## Safety summary

- **The hardware over-current trips are enabled but unproven.** All eight are
  armed while a slot runs, at ±9.5 A, above the 8 A software trip. No board has
  been seen to trip. Keep the bench supply's current limit set and stay at the
  bench until one has.
- **The host watchdog is not over-current protection.** It pauses running
  slots 30 s after the host goes quiet — a supervision timeout measured in
  seconds, not a fast trip. It does not make unattended high-current testing
  safe.
- Calibration current is **discharge** — the external supply is the sink.
- Enter DMM currents as **magnitudes**.
- Only one slot calibrates at a time. Entering on one force-exits the others.
- Calibration is refused while any slot is running a test — including a slot
  restored as `PAUSED` after a reset.
- **A slot never resumes power by itself after a reset.** A restored slot
  holds its counters and waits for an explicit command. Do not script around
  this.
- The fixed-current setpoint is clamped to 0.8 pu (about 8 A).
- A trip, an exit, a host disconnect or a unit state change all zero the
  reference before anything else changes.
- A slot driving current with no command for 120 s auto-exits.
- Remove cells from the slot before calibrating it.

---

## Known issues

None in the debug console today. The spurious
`WARNING: host watchdog DISABLED` banner that earlier revisions described here
was removed from the firmware on 2026-09-22; if you see it, the unit is
running an old build.

> ### The AT console baud rate is no longer an issue — it works at 115200
>
> Earlier revisions of this document told you to connect at ~7267 baud. That
> was wrong, and the advice is withdrawn.
>
> The console runs correctly at the configured **115200 8N1** on the
> controlCARD FTDI backchannel. What looked like a wrong baud rate was **build
> skew**: the console is served by CPU2, `SCI_setConfig()` derives BRR from
> `DEVICE_LSPCLK_FREQ`, and the clock configuration was being edited with only
> CPU1 rebuilt and reloaded. CPU2 kept running a divisor built for the previous
> clock, so the apparent baud shifted every time — which was misread as
> confirmation of a hardware fault.
>
> The clock itself was never wrong. SYSCLK measures **179.7 MHz** against a
> configured 180 MHz (20 MHz XTAL ×18 /2), 0.17 % error. LSPCLK is 45 MHz and
> the driver programs BRR = 47, giving 117188 baud — 1.7 % off 115200 and
> comfortably inside UART tolerance.
>
> **Two practical rules from this.** Rebuild and reload *both* cores after any
> clock change. And probe the console with a real command such as
> `AT+InputVoltage?` — a bare `AT` is silently ignored by design, which reads
> exactly like a dead console.

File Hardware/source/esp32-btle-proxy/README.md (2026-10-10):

# esp32-btle-proxy

BLE and WiFi proxy for the TIDA-010086 eight-channel battery test system
(BTS), with a battery test state machine on top of the raw I2C register map.

The ESP32 is the supervisor: it owns the test sequence, integrates capacity,
enforces the cell's limits, records results, and exposes all of it over both
a GATT service (for a Web Bluetooth UI) and a JSON HTTP API.

---

## Hardware

| | |
|---|---|
| Board | Wemos LOLIN32 v1.0.0, ESP-WROOM-32, with the on-board lithium charger and a backup cell |
| Target | `esp32` (Xtensa, dual core) |
| Flash | 4 MB |
| Programming port | COM6 (Silicon Labs CP210x) |
| BTS link | I2C controller, SDA = GPIO21, SCL = GPIO22, **50 kHz** (see below) |
| Status panel | ST7789 on SPI2/HSPI, MOSI = GPIO23, SCK = GPIO18, CS = GPIO19 (external 10 k pull-up), DC = GPIO16, RST = GPIO17, BL = GPIO4 |
| Slot LEDs | 8x WS2812B on SPI3/VSPI, DIN = GPIO13 |
| Encoder | A = GPIO32, B = GPIO27, switch = GPIO33 |
| KEY0 button | GPIO34 (input only, pulled up on the LCD board) |
| BTS address | `0x50` |
| Unit envelope | 0–5 V and ±10 A per channel, 8 channels |

The backup cell is why `test_engine_init()` stops the channels at boot: the
proxy can outlive a BTS power cycle, so at startup it cannot know what the
unit is doing and must not assume the channels are idle. The one exception is
a slot the BTS reports `PAUSED` — see the watchdog and pause section below.

### The I2C link runs at 50 kHz

`main.c` asks for 100 kHz, but `bts_link.c` sets the device to **50 kHz**,
and that is what runs. The BTS board pulls the bus up with only 10 kΩ, over a
ribbon, so rise time — not bandwidth — is the limit: at 100 pF a 10 k
pull-up takes ~850 ns to rise, against the 1000 ns standard mode allows. The
ESP32's internal pull-ups are enabled as well. A poll cycle is nine
transactions, so 50 kHz costs nothing that matters.

At start-up the link tries 50 kHz and 10 kHz, in both pin orders, before
falling back to the configured pins, so a swapped SDA/SCL or a marginal
harness still comes up. After any failed transfer the bus is reset
(`bus_recover()`), and the poll task does **not** scan the bus while the link
is down — ESP-IDF v6.1's `i2c_master_probe()` leaves state behind on failure
that crashed the next transfer.

### Verified on a bare ESP32, 2026-10-08

On a fresh board with no BTS attached: BLE GATT (all 12 characteristics,
reads and notifications, proto 7, with register access correctly refused —
`tools/ble_verify.py --no-bts`), the setup page, every WiFi and OTA error
path, and two full WiFi updates, one rolled back by a reset during its trial
and one confirmed. **Not yet seen:** an update confirming itself on a live
BTS link, rather than through the 180 s fallback.

---

## Building and flashing

`export.ps1` does not work on this machine — it resolves `python` from PATH
and finds the system 3.6 interpreter before the IDF venv. Use the bundled
environment script instead:

```powershell
cd esp32-btle-proxy
. .\idf_env.ps1          # sets IDF_PATH, the venv, the toolchain and ESP_IDF_VERSION
idf.py build
idf.py -p COM6 flash monitor
```

`idf_env.ps1` mirrors the paths the CCStudio ESP-IDF extension is configured
with (`idf.customExtraVars` in the editor settings). The one non-obvious
variable is `ESP_IDF_VERSION`: `idf_component_manager` reads it unconditionally
and crashes on `None` if it is unset.

The build is also driveable from the editor's ESP-IDF extension, which sets
the same environment itself.

---

## Register map v2.1 and the host watchdog

The BTS register map was reorganised in v2, and **every address moved**. Both
the C2000 and this firmware must be flashed together - there is no
compatibility window. For any individual address the authority is
`Docs/api-specification.md` §2.8;
`components/bts_link/include/bts_regs.h` is the mirror this project builds
against.

Four regions replace the nine scattered blocks of v1:

| Region | Base | Stride | Regs/slot | Range |
|---|---|---|---|---|
| runtime (RO) | 0 | 48 B | 12 | 0 – 383 |
| settings (RW) | 384 | 72 B | 18 | 384 – 959 |
| unit (mixed) | 960 | — | 27 total | 960 – 1064 |
| slot tuning (RW) | 1068 | — | 13 total | 1068 – 1116 |

**280 registers, top address 1116.** The settings stride was 24 registers
until the 2026-09-22 compression merged the charge and discharge limit pairs,
which pulled the unit base down from 1152 to 960; the slot tuning block - the
DCL biquad coefficients, one set for the whole unit - was appended above it
afterwards. Anything still quoting 1152, 1252 or a 24-register stride predates
that change.

A slot's whole live state - status, both
measurement paths, temperature and six counters - is one contiguous burst,
which took the poll cycle from **33 I2C transactions to 9** (8 slots + the
unit block; 10 while calibration is active). `eChX_MinVoltage`/`MaxVoltage`
are deleted: they were declared RO and never written.

Always derive addresses with `BTS_RT_ADDR()`, `BTS_SET_ADDR()` and
`BTS_CAL_ADDR()` rather than open-coding the arithmetic.

### The host watchdog

The unit runs a countdown, 30 s by default, reloaded by **any** host command
on any interface - including a register **read**, so this firmware's 250 ms
poll keeps it fed without a dedicated keep-alive. When it expires every
`CHARGING`/`DISCHARGING` slot is paused with `WD_TRIPPED` and its converter
off. That is the supervision this instrument previously had nowhere: before
v2, losing the ESP32 left the converters running.

**The read-path reload is load-bearing here.** This firmware's steady-state
poll issues nothing but reads, so a BTS build that reloads only in
`applyHostRegisterWrite()` would pause every running slot 30 s after the last
mode command, however healthily the proxy is polling. Verify it against the
I2C target read path, not just the write path, before trusting a long run.

It is **not** over-current protection. Hardware over-current trips are
disabled on this build and the software check in `BTS_tripEpwm()` remains the
only fast protection.

The timeout is readable and writable at `eHostWatchdog_s` (1196) and appears
in `GET /api/status` as `unit.watchdog_timeout_s`. Writing 0 disables it,
which is for bench work where nothing is polling. The unit publishes only the
configured timeout, **not the remaining seconds**, so no host can show a live
countdown - only whether supervision is armed.

### PAUSED, and why a restored slot never auto-resumes

A slot can be `PAUSED` with its `CHARGING` or `DISCHARGING` bit still set:
the converter is off, the direction is remembered and the counters are frozen
intact. Two bits say why - `WD_TRIPPED` (the host link died mid-run) and
`RESTORED` (the unit reset and rebuilt the run from F-RAM at boot).

`RESTORED` is the safety-critical one. **The engine never resumes it.** The
cell may have been swapped while the unit was off, so the run is parked in
`SLOT_STATE_BTS_PAUSED` - which is neither a fault nor an idle slot the
engine may reuse - and only an explicit operator action over HTTP or BLE
resumes it. `test_engine_init()`'s boot sweep skips a paused slot for the
same reason: stopping it would discard the state the unit deliberately kept.

Pause and resume are edge command bits in the mode register (3 and 4), acted
on at the write and not retained.

---

## One thing the BTS firmware still cannot do

Found by reading the C2000 sources. **Not a fault in this project — it is a
limitation of the BTS build in `tida-010086/bts_F2837xD_8ch/`.**

### The mAh/mWh accumulators cannot be reset on demand

The specified sequence was "reset the watt and current counters in the BTS
via registers, then initiate the discharge". The **populated** half of that is
solved on the BTS side; the **host-commanded reset** half is not:

- CPU1 integrates `Isense_A`/`Vsense_V` — the 16-bit ADS131M08 pair — in its
  `C1()` task and publishes both directions' totals in each slot's
  runtime block, now with a run-time seconds counter beside each mAh/mWh
  pair. Both accumulate positive magnitude into their own direction, so a
  charge and a discharge on one slot give two separate totals.
- They are **still `REG_ACCESS_RO`**, and `i2cSlaveISR()` still drops host
  writes to RO registers, so a host cannot zero them whenever it likes.
- What replaces that: the BTS resets a direction's set itself in
  `modeCallback()` at the moment that direction starts, and only that set.
  A pause and resume zeroes nothing, which is the point of the state.

**What this firmware does:** keeps its own trapezoidal integration
(`coulomb_counter.c`) as the reported figure, because it samples on real
elapsed time at the 250 ms poll and does not lose a partial interval at the
ends of a run. The BTS's own counters are read
each poll and reported beside it (`bts_raw` in the result JSON, `bts` in the
slot status) so the two can be compared. `try_reset_bts_accumulators()` still
issues the write for a future build that makes the registers writable.

For a slot the BTS is holding paused, the **BTS's** counters are the ones
reported: the run may predate this boot entirely, and where both exist the
BTS's kept counting up to the moment of the pause.

Note that `bts_link_stats_are_live()` is a **positive test only**: a unit that
has been idle since power-up reads all-zero and is indistinguishable from an
older firmware that never wrote these registers.

### End-of-test: the BTS terminates, the engine sequences

The C2000 now ends a phase itself and reports it as END, status bit 2
(`BTS_STATUS_FINISHED`; `BTS_STATUS_END` is an alias for it, and bit 16 is
unused). A discharge ends at `V_MIN`; a charge ends once its CV loop holds
`V_MAX` and the current has fallen to `I_MIN`. `bts_says_done()` treats END
as the end of the current phase, and the engine moves on to the next step of
the test — rest, discharge, recharge.

The engine still watches the cell voltage against its own cutoffs and can
issue the stop itself, so a unit that never asserts END still finishes a
test. Discharge termination is verified on hardware; charge termination is
not yet.

---

## Register map contract

`components/bts_link/include/bts_regs.h` is a hand-maintained mirror of
`tida-010086/bts_F2837xD_8ch/registers.h`. **There is no build coupling
between the two projects — if the C2000 map changes, update `bts_regs.h` to
match.**

Two details are easy to get wrong, and the older ESPHome component in
`esp32-controller/components/bts_i2c/` gets both of them wrong (it is also
still on the v1 map and is documented as do-not-use):

**Byte order is big-endian.** `floatGetWireByte()` in `com_cpu2.c` emits
word1-high, word1-low, word0-high, word0-low, which is the float MSB first.
A `memcpy` into a `float` on the ESP32 produces garbage. Use
`bts_wire_to_f32()` / `bts_f32_to_wire()`.

**Offsets and status bits mean different things on the two sides.** In
`bts_regs.h` the offsets are **byte** offsets and `BTS_STATUS_*` are
**masks**; the C2000 header uses register **indices** and bit **positions**.
Copying a line between the two files compiles and is silently wrong — there
is a warning block above `BTS_STATUS_RUNNING` saying so.

Register addresses on the wire are **byte** addresses (index × 4). Reads
auto-increment, so a whole block is one transaction; writes rewind to the
address phase, so a burst write must not resend the address.

Every read is preceded by one **pad byte**: the C2000 starts clocking out
whatever its transmit register holds the instant it acknowledges the repeated
start, before its ISR can run. `bus_read_block()` fetches `1 + count*4` bytes
and discards the first. A read path that omits this returns shifted garbage.

---

## Test sequence

```
IDLE
 └─ CHECK_REST      measure open-circuit voltage after a 10 s settle
     ├─ V ≥ charge_v_max × (1 − rest_tolerance_pct/100)  →  DISCHARGE
     └─ otherwise                                        →  CHARGE
 ├─ CHARGE          CC at the charge C rate, then CV, until the current
 │                  tapers to charge_term_c × capacity
 ├─ REST            the chemistry's rest_minutes; the voltage at the end is
 │                  recorded as the discharge's true start voltage
 ├─ DISCHARGE       zero the counters, then CC at the discharge C rate until
 │                  the cell reaches discharge_v_min, integrating mAh/mWh
 ├─ DISCHARGE_REST  5 min settle, then record the true rested end voltage
 ├─ RECHARGE        only when auto_recharge_to_shipping is set: put back
 │                  shipping_pct of the mAh just removed, by coulomb count
 └─ COMPLETE
```

Any state can go to `FAULT` (which must be cleared explicitly, so an operator
has to see it) or `ABORTED`. A slot can also land in `BTS_PAUSED` from any
state including `IDLE`, when the unit reports the slot paused — a watchdog
timeout, or a run restored from F-RAM at boot. That is not a fault and not an
idle slot: starting or reconfiguring it is refused until an operator resumes
or aborts it.

The recharge target is a percentage of **what this test actually removed**,
not of the datasheet capacity, so an aged cell still lands at the right state
of charge. It terminates on coulomb count rather than voltage, because
resting voltage is a poor SoC proxy on a flat-plateau chemistry like LFP;
`charge_v_max` remains a hard backstop.

### Safety supervision

Every tick, on every active state: over/under temperature against the cell's
profile, over-current against the setpoint (30% margin, after a 2 s ramp
allowance), the BTS CMPSS and GPIO trip bits, the unit's input-voltage state,
a wall-clock ceiling (12 h by default), and the I2C link itself. A sustained
comms blackout stops every channel, so a dropped link cannot leave a cell on
load indefinitely.

The BTS's own 30 s host watchdog now backs that up from the other side: if
this firmware stops polling entirely, the unit pauses every running slot
itself rather than leaving the converters on.

This is the *slow supervisory* layer. The BTS's own CMPSS and GPIO trips are
the fast one, in hardware, and they stay authoritative.

---

## Cell definitions

`components/cell_profiles/` carries a two-layer model: a **chemistry** sets
the voltage envelope and default C rates; a **cell model** pins the capacity
and the manufacturer's continuous current ratings. Selecting a model implies
its chemistry. A user-entered capacity always wins, because aged cells are
the normal case.

Chemistries: **LCO, LTO, LFP, NMC, NCA**.

LTO is the outlier and is worth checking if something looks wrong: 2.4 V
nominal, 2.8 V max, **1.5 V** cutoff, and it tolerates sub-zero charging.
A NMC-shaped assumption would cut it off at 2.5 V and report roughly half
its capacity.

Models: **20Q, 25R, 30Q, 30R** (Samsung INR18650), **VTC3, VTC4, VTC5,
VTC5A, VTC6** (Sony/Murata).

Resolution order, in `cell_profile_resolve()`:

1. chemistry defaults
2. model overrides (capacity, datasheet voltages)
3. user capacity override
4. the cell's own continuous current rating
5. the unit envelope (±10 A, 0–5 V)

Chemistry profiles can be overridden at runtime and are persisted to NVS, so
a site can retune a cutoff without a firmware build.

---

## Slot indicators

Eight WS2812B pixels, one per BTS slot, are driven from this firmware —
`components/led_strip/`, one `SPI3_HOST` transfer every 25 ms from a FreeRTOS
task at priority 4. Colour comes from `bts_link_get_snapshot()`, so the
indicators ride on the poll that was already running and there is nothing to
feed them.

**This used to be the C2000's job, and it never lit a single pixel.**
`LEDDriver_update()` clocked raw colour bytes out of SCIA at 800 kbaud, but a
WS2812B decodes pulse *widths* — 400 ns high is a 0, 800 ns high is a 1, each
inside a 1250 ns slot — and a UART cannot produce them: it forces a low start
bit before every byte and holds each data bit for a full bit time, so the strip
saw framing noise and latched nothing. Fixing it in place needed a peripheral
that emits a free-running bit pattern, which on that device means SPI — and
GPIO29, the wire that physically exists, has no SPI mux option, while both
usable SPI ports are held by the ADS131M08 pair. The full account, including
the per-slot colour priority chain, is in
[`Docs/supervision-and-state-design.md` §2.5.1](../Docs/supervision-and-state-design.md#251-slot-indication--the-ws2812b-string).

**SPI3 and not SPI2.** The ST7789 panel holds SPI2, which *is* HSPI: it sits on
GPIO23/GPIO18 — VSPI's IO_MUX default pads — but reaches them through the GPIO
matrix, so SPI3 was the genuinely free host. Sharing one would let an LED frame
stall a panel repaint and vice versa.

**Four SPI bits per WS2812B bit at 2.5 MHz** (80 MHz / 32, so one SPI bit is
400 ns): `1000` is a 0, `1100` is a 1, landing both symbols on the part's exact
nominal widths with a 1600 ns slot well inside the 650–1850 ns it tolerates.
Two WS2812B bits pack into one SPI byte, so the whole eight-LED frame is 96
bytes in a single 307 us DMA transfer, and MOSI rests low afterwards — which
covers the 50 us reset latch for free. The rate is a deliberate departure from
the commonly-cited **3.333 MHz**, where the same `1100` symbol gives
T1H = 600 ns, *below* the 650 ns minimum for a logic 1. That works on some
strips and fails on others, which on a safety indicator is the worst failure
mode available.

**The encoder's B channel moved from GPIO13 to GPIO27** to free the MOSI pin.
GPIO14 was the other candidate and was rejected: it is MTMS, and a JTAG pin on
the encoder would make the box awkward to debug later. GPIO27 carries no
strapping or JTAG role. A and the switch have since moved off GPIO15 and GPIO2,
which are strapping pins, to GPIO32 and GPIO33. Full pin map:
[`Docs/esp32-hardware-connections.md`](../Docs/esp32-hardware-connections.md).

### What it costs

**Indication lags by up to one poll.** Colour derives from the 250 ms I2C
snapshot rather than from the unit's registers directly, so a state change can
take ~250 ms longer to reach the strip than a C2000-resident driver would have
needed. Against an operator's reaction time that is nothing; it is recorded
because it is a real difference.

**The strip now depends on this firmware being alive.** If the ESP32 is
unplugged, crashes, or is held in reset it sends no frames at all — and a
WS2812B latch holds its last colour **indefinitely**, leaving a pixel that
still shows a slot running when it has since tripped. All eight flashing
amber in unison covers the case where this firmware is running but cannot
reach the unit; by construction it cannot cover this firmware being dead.
Treat the strip as an indicator, never as evidence that a slot is safe.

---

## BLE interface

One primary service, `e5f10001-9a4c-4b7d-8f2e-1c3a5b7d9f01`. Every
characteristic shares the base with a 16-bit discriminator in bytes 2–3.

| UUID suffix | Access | Payload |
|---|---|---|
| `0002` | read, notify | `ble_unit_status_t` |
| `0003` | write | `ble_cmd_t` — start / abort / clear fault / abort all / pause / resume |
| `0004` | read, write | `uint8` slot select |
| `0005` | read, write | `ble_slot_config_t` |
| `0006` | read | `ble_slot_result_t` |
| `0007` | write | UTF-8 barcode for the selected slot |
| `0008` | read, write | `uint8` catalogue index |
| `0009` | read | `ble_catalog_entry_t` |
| `000a` | read, notify | `ble_slot_status_t` |
| `000b` | write | `ble_cal_cmd_t` |
| `000c` | read, notify | `ble_cal_status_t` |
| `000d` | read, write | `ble_register_cmd_t` - raw register access |

All records are packed little-endian, which is what `DataView` with
`littleEndian=true` reads — note this is the *opposite* of the BTS I2C wire
format; nothing past `bts_link` sees the C2000's byte order.

`ble_proto.h` is the contract. `BLE_PROTO_VERSION` is **7**, published in the
unit-status record so a client can refuse to decode a firmware it does not
understand rather than silently misreading a struct. The interface is
**append-only**: a newer version adds characteristics and appends fields, so
every offset an older client decodes stays put and no characteristic is ever
renumbered - the discriminators are the client's contract.

| Version | What it added |
|---|---|
| 3 | The watchdog timeout on `ble_unit_status_t` (24 B), and the pause flags and six counters on `ble_slot_status_t` |
| 4 | Characteristic `000d`, raw register access - this is what lets a BLE client reach the C2000 mode register, and so charge and discharge, at all |
| 6 | The two CC/CV regulation flags at the end of the slot record (70 B) |
| 7 | The four pre-charge balance flags - waiting, balancing, ready, soft start (74 B) |

`tools/ble_verify.py` decodes every readable characteristic, checks the
version first, and fails rather than misreading a shorter record.

The slot-status notification carries its slot number, so one subscription
covers all eight. Notifications fire on every state change, and once a second
while anything is running.

The 128-bit service UUID is advertised in the **scan response** — with the
device name it will not fit in the 31-byte advertising payload, and Web
Bluetooth needs it present to offer the device in a filtered chooser.

Disconnecting does **not** abort running tests. A multi-hour discharge has to
survive an operator walking away with the tablet.

---

## HTTP API

| Method | Path | |
|---|---|---|
| GET | `/api/status` | unit + all slots, with the watchdog timeout and per-slot pause flags and counters |
| GET | `/api/slot/<n>` | one slot, with its resolved profile and last result |
| POST | `/api/slot/<n>/config` | all fields optional; unspecified fields keep their current value |
| POST | `/api/slot/<n>/start` · `/abort` · `/clear` | |
| POST | `/api/slot/<n>/pause` · `/resume` | pause a running slot, or resume one the BTS is holding |
| POST | `/api/slot/<n>/serial` | `{"serial":"..."}` |
| GET | `/api/slot/<n>/result` | |
| GET | `/api/results?offset=&limit=` | rolling history, 64 deep |
| GET | `/api/catalog` | chemistries and cell models |
| POST | `/api/chemistry/<name>` | override and persist a chemistry profile |
| POST | `/api/abort_all` | |
| GET | `/` | the setup page: unit state, WiFi and firmware update |
| GET | `/api/wifi` | station SSID, join state, addresses. Never the password |
| POST | `/api/wifi` | `{"ssid":"...","password":"..."}` |
| GET | `/api/ota` | running version and slot, trial state, whether a key is set |
| POST | `/api/ota/key` | `{"current":"...","key":"..."}` — set or change the update key |
| POST | `/api/ota` | raw `.bin` body, `X-OTA-Key` header — firmware update |
| GET | `/api/registers?addr=&count=` | raw BTS registers, for bring-up |

Route ordering matters and is not obvious: `httpd_uri_match_wildcard()`
honours only a **trailing** asterisk, so a pattern with the wildcard in the
middle never matches. Exact paths are registered before the wildcards, one
wildcard pattern is registered per method, and the trailing action segment is
dispatched by hand — see the comment on the route table.

Example. There is no mDNS responder in this firmware, so use the address the
device logs on connect (`idf.py monitor`) rather than a `.local` name:

```bash
BTS=192.168.1.50   # from the boot log
curl -X POST http://$BTS/api/slot/0/config \
  -d '{"model":"VTC6","serial":"ABC123","auto_recharge_to_shipping":true}'
curl -X POST http://$BTS/api/slot/0/start
curl http://$BTS/api/status

# A slot that came back paused after a BTS reset, once the cell is confirmed:
curl -X POST http://$BTS/api/slot/0/resume
```

JSON is emitted and parsed by `json_min.c` rather than cJSON: IDF 6.1 no
longer bundles cJSON (it is a registry component fetched at configure time),
this project has to build offline, and the documents involved are flat and
fixed-shape.

WiFi comes up as APSTA. Stored station credentials are joined if present; the
SoftAP stays up either way, so a tester whose site network changed is still
reachable. The AP is open by default — a WPA2 key baked into shipped firmware
is not a security boundary; the bench network is.

### Joining a network from the setup page

Join the `BTS-Tester` access point and browse to `http://192.168.4.1/`. The
WiFi card takes an SSID and password, saves them to flash and joins at once;
the AP stays up throughout, so a wrong password costs nothing but a retry.

After five failed joins the station stops retrying continuously. The ESP32
has one radio, so every attempt to find the saved network takes the AP off
its channel for a scan; a client notices the beacons stop, drops the AP and
takes its own time to rejoin. So the retry period depends on whether anyone
is on the AP:

| | Retry every | Measured, laptop on the AP, saved network absent |
|---|---|---|
| Nobody on the AP | **30 s** | — (nothing to disturb) |
| A client on the AP | **5 min** | page answered 44 of 48 probes over 4 min; the 4 misses were the first 20 s, before the backoff took hold |

A flat 30 s cadence, tried first, left the page unreachable for about 20 s of
every 35 — usable, but not for typing a password.

To stop it looking at all, **Forget network** on the setup page (or
`POST /api/wifi` with `{"ssid":""}`) erases the saved credentials; the AP is
then steady.

The password is write-only: `GET /api/wifi` never returns it, because anything
it returned would be readable by anyone in range of the open AP.

---

## Firmware update over WiFi

Two app slots, `ota_0` and `ota_1`. An upload is written into whichever is not
running, the boot slot is switched, and the proxy restarts into it.

**A new image is on trial until the BTS answers.** Rollback is enabled
(`CONFIG_BOOTLOADER_APP_ROLLBACK_ENABLE`), so the bootloader marks a freshly
written image `PENDING_VERIFY`. `components/ota` confirms it once the BTS link
completes a poll — real registers back over I2C, not merely "it booted". An
image that never gets there and is rebooted is **rolled back** to the previous
slot automatically.

That cannot be the only rule: the proxy has a backup cell and often runs with
the rack powered down, and an image that waited forever for the link would be
rolled back by the next power blip. So after **180 s** without a link it is
confirmed anyway, and the log says it was confirmed *without* the BTS. Such an
image is still on WiFi, so it can always be replaced by another upload.

### Doing an update

1. Set an update key once (uploads are refused until there is one):
   on the setup page, or
   `curl -X POST http://$BTS/api/ota/key -d '{"key":"choose-one"}'`.
2. Build as normal; the image is `build/bts_btle_proxy.bin`.
3. Upload it from the setup page, or:

   ```bash
   curl -X POST http://$BTS/api/ota -H "X-OTA-Key: choose-one" \n        --data-binary @build/bts_btle_proxy.bin
   ```

4. The proxy restarts. `GET /api/ota` shows `pending_verify: true` until the
   BTS answers, then `confirmed: true`.

The upload is checked before any of it is accepted: an image for another chip,
another ESP-IDF project, or not an app at all (a bootloader or partition table
posted by mistake) is refused from its first 288 bytes, before a megabyte goes
over the air. The whole image is then hash-checked before the boot slot moves.

**An update is refused while any slot is running** (`409`). The restart stops
every slot that is not paused — `test_engine_init()` has to, since a freshly
booted proxy cannot know what an unheld channel is doing — so an update in the
middle of a shift would end every test. Pause or finish them first, or add
`?force=1` to the URL if you mean it.

### What the key is, and is not

The key stops an accidental upload and casual access on a bench LAN. **It is
not a security boundary.** It is set through the same unauthenticated API
(trust on first use): the first set needs nothing, every later change needs the
current key. So it protects a unit provisioned before an attacker reached it,
and not one provisioned after. The rest of the API has no authentication at
all. If that matters on your network, the answer is the network.

### First flash after enabling rollback

Rollback changes the **bootloader**, not just the app. The first time, flash
everything over USB (`idf.py -p COM6 flash`), not just the app — an old
bootloader ignores the trial state, and every later OTA image would be
accepted without confirmation.

---

## Layout

```
main/main.c                        init order and board wiring
components/bts_link/               I2C transport, 250 ms poll task, snapshot
  include/bts_regs.h               the register map contract
components/cell_profiles/          chemistries, cell models, resolution
components/test_engine/            the state machine
  coulomb_counter.c                local mAh/mWh integration
  result_store.c                   NVS ring buffer in the `results` partition
components/ble_svc/                NimBLE GATT server
  include/ble_proto.h              the BLE wire contract
components/web_api/                HTTP API, WiFi, minimal JSON
```

NimBLE rather than Bluedroid: with dual OTA slots in 4 MB, the ~100 kB
Bluedroid costs over NimBLE for a peripheral-only role is not affordable.

Results live in a **separate NVS partition** from the default one, so filling
it with test history cannot displace the chemistry overrides or the WiFi
credentials.

There is no factory partition — with a blank `otadata` the bootloader runs
`ota_0`, so a factory slot would only cost a third of the flash to hold a
copy of the same image.

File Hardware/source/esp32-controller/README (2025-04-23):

Use espHome to compile this application.

Will update the how to later. components access a HID barcode scanner and a i2c interface to the C28 CPU

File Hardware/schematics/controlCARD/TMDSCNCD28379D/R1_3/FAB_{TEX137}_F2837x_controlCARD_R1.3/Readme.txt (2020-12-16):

Company Name:		TEXAS INSTRUMENTS, C2000
PC Board Name:		F2837x controlCARD      
PC Board Number:		F2837x controlCARD
Revision:			1.3
Design House:		Willow Spring Technical Services, Corp.
Job Number: 		TEX137

Designed by:          Carl Sangiolo
Contact Number:       (508) 947 - 2709
e-mail:               carl@wstscorp.com
Files Included:

Filename		Description						Format
--------		-----------						------
L1.PHO			Primary Side Cu					Gerber 8.5
L2.PHO			Internal Plane 1 (NEG)          Gerber 8.5
L3.PHO			Internal Signal 1				Gerber 8.5			
L4.PHO			Internal Signal 2				Gerber 8.5
L5.PHO			Internal Plane 2 (NEG)          Gerber 8.5
L6.PHO			Internal Plane 3 (POS)          Gerber 8.5	
L7.PHO			Internal Signal 3				Gerber 8.5	
L8.PHO			Internal Signal 4				Gerber 8.5	
L9.PHO			Internal Plane 4 (NEG)          Gerber 8.5	
L10.PHO			Secondary Side Cu				Gerber 8.5
PSS.PHO			Primary Silkscreen A/W			Gerber 8.5
SSS.PHO			Secondary Silkscreen A/W        Gerber 8.5
PSM.PHO			Primary Soldermask A/W			Gerber 8.5
SSM.PHO			Secondary Soldermask A/W 		Gerber 8.5
PST.PHO			Primary Solder Stencil A/W 		Gerber 8.5
DD.PHO			Drill Drawing  					Gerber 8.5
NC_DRILL.DRL		NC Drill Data					NC DRILL ASCII																
NC_DRILL.REP		Drill Tool Listing				ASCII
NC_DRILL.LST		Drill X-Y Listing				ASCII
IPCD356.NET		IPC-D-356 Netlist				IPC-D-356 ASCII
README.TXT   	This File						ASCII

NOTES: 

1) USE FILM OUTLINE CORNERS TO ALIGN ARTWORKS

2) ALL THERMALS ARE O.D.  I.D.= O.D. - .020
   WITH A .015 OPEN AT 45 DEGREES.

3) ALL VIAS SHALL HAVE A DIRECT CONNECTION
   TO THE PLANE. NO THERMALS ON VIAS.

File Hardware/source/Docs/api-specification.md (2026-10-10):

# API Specification — HTTP and I2C

The two non-BLE interfaces of the eight-channel battery test system (BTS):

- **Part 1 — HTTP**, served by the ESP32 proxy on the LAN. The interface for
  a browser, for scripted integration, and for bulk retrieval of the result
  history.
- **Part 2 — I2C register map**, the ESP32's own link to the TI F2837xD, and
  the interface for any other host that wants to talk to the unit directly.

The BLE interface is in [`ble-specification.md`](ble-specification.md); the
calibration engineering contract is in
[`calibration-design.md`](calibration-design.md).

Everything here is read from source. Where the firmware declares something it
never writes, that is called out rather than glossed over.

---

## Read this first: the endianness split

> **HTTP carries JSON numbers — no byte order applies. The I2C register wire
> format is BIG-endian. The BLE records are LITTLE-endian.**
>
> The C2000 is a 16-bit-word machine whose `floatGetWireByte()`
> (`com_cpu2.c:2350-2355`) emits a float most-significant byte first. The
> conversion happens in `bts_regs.h` (`bts_wire_to_f32()` /
> `bts_f32_to_wire()`), and nothing above `bts_link` — not the HTTP layer,
> not BLE — ever sees the C2000's byte order.
>
> If you are writing an I2C client of your own, this is the single detail
> most likely to cost you an afternoon, alongside the lead-in pad byte in
> §2.3. Use a shift-and-OR through a `uint32_t`, not a `memcpy` of a float:
> the helpers in `bts_regs.h` are written that way precisely so they are
> correct regardless of the host's own byte order.

---

# Part 1 — HTTP API

Implemented in `esp32-btle-proxy/components/web_api/web_api.c` on
`esp_http_server`.

| | |
|---|---|
| **Port** | 80 (`web_api_config_t.port`, 0 → 80) |
| **Content type** | `application/json` on every response |
| **Endpoints** | 33 (see §1.1) |
| **Route table entries** | 20 (`s_routes[]` in `web_api.c`) |
| **Authentication** | **None**, except firmware upload (`X-OTA-Key`, §1.11.2) |
| **Encryption** | **None** — plain HTTP |
| **Network** | WiFi station, with SoftAP fallback (`BTS-Tester`, open) if no credentials are stored or the join fails |

There is no captive portal and no login. A tester that cannot be talked to
because someone changed the WiFi password is worse than an open AP on a bench
network — but do not put this device on an untrusted one.

## 1. Endpoints

### 1.1 Summary

| # | Method | URI | Purpose |
|---|---|---|---|
| 1 | GET | `/api/status` | Unit plus all eight slots |
| 2 | GET | `/api/slot/<n>` | One slot, with its resolved profile and last result |
| 3 | GET | `/api/slot/<n>/result` | That slot's latest result alone |
| 4 | POST | `/api/slot/<n>/config` | Set slot configuration; every field optional |
| 5 | POST | `/api/slot/<n>/serial` | Set the slot's serial/barcode |
| 6 | POST | `/api/slot/<n>/start` | Start the test |
| 7 | POST | `/api/slot/<n>/abort` | Abort the test |
| 8 | POST | `/api/slot/<n>/clear` | Clear the slot's fault |
| 9 | POST | `/api/slot/<n>/pause` | Pause the slot, keeping its counters |
| 10 | POST | `/api/slot/<n>/resume` | Resume a paused slot |
| 11 | POST | `/api/abort_all` | Abort every slot |
| 12 | GET | `/api/results` | Paged result history across all slots |
| 13 | GET | `/api/catalog` | Chemistries and cell models |
| 14 | POST | `/api/chemistry/<name>` | Override a chemistry profile, persisted to NVS |
| 15 | POST | `/api/wifi` | Store station credentials |
| 16 | GET | `/api/registers` | Raw BTS register block read |
| 17 | POST | `/api/registers` | Raw BTS register write |
| 18 | GET | `/api/i2c_diag` | Bus-level I2C diagnostic |
| 19 | GET | `/api/calibration` | Full calibration state, telemetry and persisted gains |
| 20 | POST | `/api/calibration/enter` | `CAL_CMD_ENTER` |
| 21 | POST | `/api/calibration/exit` | `CAL_CMD_EXIT` |
| 22 | POST | `/api/calibration/clear` | `CAL_CMD_CLEAR` |
| 23 | POST | `/api/calibration/voltage` | `CAL_CMD_CAPTURE_VOLTAGE` |
| 24 | POST | `/api/calibration/zero_current` | `CAL_CMD_ZERO_CURRENT` |
| 25 | POST | `/api/calibration/fixed_current` | `CAL_CMD_SET_FIXED_CURRENT` |
| 26 | POST | `/api/calibration/current` | `CAL_CMD_CAPTURE_CURRENT` |
| 27 | POST | `/api/calibration/save` | `CAL_CMD_COMPUTE_SAVE` |
| 28 | OPTIONS | `/*` | CORS preflight |
| 29 | GET | `/` (and `/index.html`) | The setup page — HTML, not JSON |
| 30 | GET | `/api/wifi` | Station SSID, join state and addresses; never the password |
| 31 | GET | `/api/ota` | Running image, trial state, whether an update key is set |
| 32 | POST | `/api/ota/key` | Set or change the update key |
| 33 | POST | `/api/ota` | Firmware upload — raw `.bin`, keyed |

`<n>` is a **0-based** slot index, 0 to 7. Front-panel slot 3 is
`/api/slot/2`.

### 1.2 Common response shapes

**Success with no payload** — `send_ok()`:

```json
{"ok":true}
```

**Error** — `send_error()`, on every 4xx and 5xx it raises:

```json
{"ok":false,"error":"human-readable reason"}
```

> **One error path does not follow the pattern.** If a response overflows the
> 6144-byte buffer, `send_json()` emits `500 Internal Server Error` with the
> body `{"error":"response too large"}` — no `"ok"` key — **and it does not
> set the CORS header** (`web_api.c:43-48`). A browser sees an opaque network
> failure rather than the 500. This is reachable in practice only on
> `/api/slot/<n>`, which is the largest non-chunked response.

Numbers are emitted with a fixed number of decimals by `json_kv_f()`; the
tables below give the precision where it matters.

---

### 1.3 `GET /api/status`

Unit state plus every slot. **Chunked** — the response grows with the number
of configured slots and exceeds the buffer at eight, so it is flushed between
array elements.

Query parameters: none.

```json
{
  "unit": {
    "online": true,
    "unit_state": 2,
    "input_voltage_v": 12.041,
    "trip_status": 0,
    "consecutive_errors": 0,
    "watchdog_timeout_s": 30,
    "watchdog_enabled": true,
    "slots": 8,
    "max_current_a": 10.0,
    "max_voltage_v": 5.0,
    "bts_accumulators_live": false,
    "uptime_s": 4211,
    "wifi_sta": true,
    "wifi_ap": false
  },
  "slots": [ { /* see below */ } ]
}
```

| Key | Type | Meaning |
|---|---|---|
| `unit.online` | bool | The last I2C poll cycle to the BTS completed |
| `unit.unit_state` | 0–4 | See §1.3.1 |
| `unit.input_voltage_v` | float, 3 dp | DC input bus, register 1176 |
| `unit.trip_status` | uint32 | Two bits per channel. Set by a hardware trip; cleared when the slot is restarted — see §2.7 |
| `unit.consecutive_errors` | uint32 | Failed poll cycles in a row; 0 when healthy |
| `unit.watchdog_timeout_s` | float, 0 dp | The unit's configured host-watchdog timeout, register 1196. **0 = disabled** |
| `unit.watchdog_enabled` | bool | `watchdog_timeout_s > 0`. Convenience only, derived from the field above |
| `unit.slots` | int | 8 |
| `unit.max_current_a` | float, 1 dp | 10.0, the unit envelope from `BTS_CMPSS_FULLSCALE_A` |
| `unit.max_voltage_v` | float, 1 dp | 5.0, the per-channel output range |
| `unit.bts_accumulators_live` | bool | Positive test only — see §1.3.2 |
| `unit.uptime_s` | uint32 | ESP32 uptime, not a wall clock |
| `unit.wifi_sta` / `wifi_ap` | bool | Station joined / SoftAP active |

> **There is no remaining-seconds field.** The BTS publishes a live countdown
> at `eWatchdogRemaining_s` (**1028**), and the ESP32 mirror now declares it,
> but no HTTP or BLE field carries it onward. A host that wants the countdown
> reads it directly through `GET /api/registers?addr=1028&count=1`.

Each element of `slots`:

| Key | Type | Meaning |
|---|---|---|
| `slot` | 0–7 | Slot index |
| `state` | string | `IDLE`, `CHECK_REST`, `CHARGE`, `REST`, `DISCHARGE`, `DISCHARGE_REST`, `RECHARGE`, `COMPLETE`, `FAULT`, `ABORTED` |
| `fault` | string | `NONE`, `OVER_TEMP`, `UNDER_TEMP`, `OVER_CURRENT`, `CMPSS_TRIP`, `GPIO_TRIP`, `TIMEOUT`, `BTS_OFFLINE`, `UNIT_STATE`, `NO_CELL`, `CELL_REVERSED`, `COMMS` |
| `configured` | bool | A cell profile has been applied |
| `voltage_v` | float, 3 dp | Cell volts, **12-bit internal ADC** (register `eChX_CellVoltage`) |
| `current_a` | float, 3 dp | Cell amps, same path. Negative = discharge |
| `temp_c` | float, 1 dp | Cell temperature, from the ADS1119 converters |
| `live_mah` / `live_mwh` | float, 1 dp | ESP32-integrated charge and energy for the current phase |
| `progress` | float, 3 dp | 0..1 and beyond |
| `elapsed_s`, `state_elapsed_s` | uint32 | Seconds since test start / state entry |
| `bts_status` | uint32 | Raw BTS status word, see §2.7 |
| `serial` | string | The slot's serial, possibly empty |
| `bts` | object | **The BTS's own view of the slot.** Always present. See below |
| `config` | object | Present **only when `configured`** |
| `profile` | object | Present only when `configured`; the resolved envelope after clamping |

`last_result` is **omitted** from this endpoint to keep the poll response
small. Fetch it from `/api/slot/<n>` or `/api/results`.

The `bts` object carries the unit's own state and counters for the slot,
decoded from its status word and runtime block. It is the only place the six
per-direction counters surface as named JSON:

```json
"bts": {
  "paused": true,
  "watchdog_tripped": false,
  "restored": true,
  "ended": false,
  "const_voltage": true,
  "const_current": false,
  "charge_mah": 1842.3,
  "charge_mwh": 6871.9,
  "charge_seconds": 4380,
  "discharge_mah": 0.0,
  "discharge_mwh": 0.0,
  "discharge_seconds": 0
}
```

| Key | Type | Meaning |
|---|---|---|
| `paused` | bool | Status bit 15. The slot is held; its direction bit still says what a resume would do |
| `watchdog_tripped` | bool | Status bit 17. Paused **because the host link went quiet** |
| `restored` | bool | Status bit 18. Paused **because the unit reset mid-run** and came back holding the counters |
| `ended` | bool | Status bit 2. Test finished normally — set by the firmware's `serviceTermination()`: a charge that reached `I_MIN` while in CV, or a discharge that reached `V_MIN` |
| `const_voltage` | bool | Status bit 6. The CV half of the CCCV loop is regulating — the cell is at its voltage limit and the current is tapering toward termination |
| `const_current` | bool | Status bit 7. The CC half is regulating. Exactly one of the two is set while a slot runs; both are false when it is not |
| `charge_mah` / `charge_mwh` | float, 1 dp | Charge-direction totals |
| `charge_seconds` | float, 0 dp | Seconds spent charging this run |
| `discharge_mah` / `discharge_mwh` | float, 1 dp | Discharge-direction totals |
| `discharge_seconds` | float, 0 dp | Seconds spent discharging this run |

> **`restored` is the one an operator has to act on.** It means the unit
> reset while this slot was running. The cell may have been changed in the
> meantime, so the proxy will not auto-resume — resuming is a deliberate user
> action over HTTP or BLE. See §2.10.

`config`: `chemistry`, `model`, `capacity_mah` (0 dp), `charge_c` /
`discharge_c` (2 dp), `auto_recharge_to_shipping`, `shipping_pct` (1 dp),
`max_duration_minutes`.

`profile`: `chemistry`, `model`, `capacity_mah`, `charge_v_max`,
`discharge_v_min`, `storage_v`, `charge_current_a`, `discharge_current_a`,
`charge_term_current_a`, `temp_min_c`, `temp_max_c`, `rest_tolerance_pct`,
`rest_minutes`.

Status: `200` always. A BTS that is offline shows as `unit.online: false`,
not as an HTTP error.

#### 1.3.1 `unit_state`

| Value | Meaning |
|---|---|
| 0 | `INPUT_LOW_CHARGE_DISABLED` — input below `eChargeDisableV` (default 9.0 V). **No slot will start.** |
| 1 | `INPUT_LOW_CHARGE_RESTRICTED` — below `eChargeRestrictV` (default 10.0 V); charge refused |
| 2 | `INPUT_OK` |
| 3 | `INPUT_HIGH_DISCHARGE_RESTRICTED` — above `eDischargeRestrictV` (default 15.0 V); discharge refused |
| 4 | `INPUT_HIGH_DISCHARGE_DISABLED` — above `eDischargeDisableV` (default 16.0 V) |

#### 1.3.2 `bts_accumulators_live`

`bts_link_stats_are_live()` probes the BTS accumulators once at start-up.
The current C2000 firmware **does** populate them (§2.8.1), but the probe is
a **positive test only**: a unit that has been idle since power-up reads
all-zero and the flag stays `false`, exactly as it did on the older firmware
that never wrote them at all. A `false` here does not mean the accumulators
are dead.

Either way the ESP32 keeps its own integration (`coulomb_counter.c`) as the
reported `live_mah` / `live_mwh`, because it samples on real elapsed time at
the 250 ms poll rather than the BTS's fixed 150 ms step. The flag only says
whether the BTS figures are worth comparing against; the figures themselves
are always in the slot object's `bts{}`.

---

### 1.4 `GET /api/slot/<n>`

One slot. Same object as a `/api/status` array element, **plus**
`last_result` (the same shape as `result` in §1.6). Not chunked.

| Status | When |
|---|---|
| `200` | OK |
| `404` | `{"ok":false,"error":"bad slot"}` — the segment is missing, non-numeric, or ≥ 8 |
| `500` | Response exceeded the buffer — see the caveat in §1.2 |

---

### 1.5 `POST /api/slot/<n>/config`

Every field is optional. **The handler starts from the slot's current
configuration**, so a body of `{"serial":"ABC123"}` changes the serial and
nothing else — it does not reset the chemistry (`web_api.c:405-412`).

| Field | Type | Validation |
|---|---|---|
| `chemistry` | string | One of `LCO`, `LTO`, `LFP`, `NMC`, `NCA`, case-insensitive. Unknown → 400 |
| `model` | string | Must match a catalogue model, or be `""`. Unknown → 400; longer than 23 chars → 400 |
| `serial` | string | ≤ 31 chars. **Rejected, not truncated**, if longer — a half-written barcode on a test record looks like a genuine serial |
| `capacity_mah` | number | 0 → the model's default |
| `charge_c` | number | C-rate; 0 → the chemistry's default |
| `discharge_c` | number | C-rate; 0 → the chemistry's default |
| `shipping_pct` | number | Must be `> 0` and `<= 100`, else 400. `<= 0` after merge → 60.0 |
| `max_duration_minutes` | number | Cast to `uint32`. 0 → no limit |
| `auto_recharge_to_shipping` | bool | |

**Response:** the slot object (as in §1.3, without `last_result`) so the
client sees the **resolved** profile rather than what it asked for. The
profile is clamped to the unit envelope — 10 A and 5 V — before it reaches
the power stage.

| Status | When |
|---|---|
| `200` | Applied; body is the slot object |
| `400` | Body larger than 1024 bytes, or a validation failure above |
| `404` | Bad slot |
| `409` | `{"ok":false,"error":"slot is running"}` |

---

### 1.6 `POST /api/slot/<n>/serial`

```json
{"serial": "ABC123456"}
```

| Status | When |
|---|---|
| `200` | `{"ok":true}` |
| `400` | Missing body, or no `serial` key |
| `404` | Bad slot |
| `500` | `test_engine_set_serial()` failed |

### `GET /api/slot/<n>/result`

```json
{
  "slot": 2,
  "result": {
    "valid": true,
    "serial": "ABC123456",
    "model": "30Q",
    "chemistry": "NMC",
    "start_voltage_v": 4.198,
    "end_voltage_v": 2.502,
    "rested_voltage_v": 3.114,
    "discharge_mah": 2941.3,
    "discharge_mwh": 10284.7,
    "max_temp_c": 38.2,
    "max_current_a": 3.000,
    "min_voltage_v": 2.498,
    "max_voltage_v": 4.201,
    "discharge_seconds": 3529,
    "recharged": true,
    "recharge_mah": 1764.0,
    "shipping_voltage_v": 3.712,
    "bts_raw": {"live": true, "discharge_mah": 3481.2, "discharge_mwh": 12208.6,
                "charge_mah": 1771.4, "charge_mwh": 6537.0},
    "completed_uptime_s": 21480
  }
}
```

When no result is stored, `result` is `{"valid":false}` and nothing else.

> **`completed_uptime_s` is ESP32 uptime in seconds, not a Unix epoch.** The
> device has no real-time clock (`test_engine.c:366`). The BLE record calls
> the same value `completed_unix`, which is a misnomer; this endpoint's name
> is the honest one. Apply a wall-clock timestamp at the moment you retrieve
> the result.

`bts_raw` is the unit's own accumulators, reported so a comparison against
the ESP32's integration is possible. They **are** populated by the current
firmware — see §2.8.1. `live` is the `bts_link_stats_are_live()` probe, which
is a positive test only and stays false on a unit that has been idle since
power-up (§1.3.2).

---

### 1.7 `POST /api/slot/<n>/start` · `/abort` · `/clear` · `/pause` · `/resume`

No body. All five return `{"ok":true}` on success.

| Action | Calls | Effect on the BTS |
|---|---|---|
| `/start` | `test_engine_start(n)` | Mode write with RUN + direction. Zeroes the starting direction's counter set |
| `/abort` | `test_engine_abort(n)` | Mode write of `0x00`. Zeroes nothing |
| `/clear` | `test_engine_clear_fault(n)` | Clears the proxy's own fault latch, and sends the unit `BTS_MODE_CLEAR_FAULT` so its trip indication clears too |
| `/pause` | `test_engine_pause(n)` | Mode bit 3. Converter reference to zero, direction remembered, **counters frozen and kept** |
| `/resume` | `test_engine_resume(n)` | Mode bit 4. Resumes the held direction, **zeroes nothing**, clears `WD_TRIPPED` and `RESTORED` |

| Status | When |
|---|---|
| `200` | Accepted |
| `404` | Bad slot, or an unrecognised action segment |
| `409` | `"slot is not in a state that accepts this action"` — including a resume on a slot that is not paused |
| `500` | Any other engine error, with the `esp_err_t` name as the message |

> **The action is matched on the trailing segment, exactly.**
> `h_slot_action()` takes `strrchr(uri, '/')` and `strcmp`s it, so
> `/api/slot/2/please_start_now` is a 404 rather than a start
> (`web_api.c:533-575`). This replaced an earlier `strstr()` over the whole
> URI, which had to be abandoned when pause and resume arrived: under
> substring matching `/resume` contains no other action's name, but the
> ordering of the tests became load-bearing in a way nothing in the URI
> expressed. Exact segment matching removes the trap. The `/config` and
> `/serial` dispatchers ahead of it are unchanged.

`/pause` and `/resume` are the host-initiated half of the PAUSED state. The
other two entries into it — a watchdog timeout and a boot restore — happen on
the unit and surface through `bts.watchdog_tripped` / `bts.restored` in
§1.3. A restored slot **must not** be auto-resumed; see §2.10.

### `POST /api/abort_all`

No body, no failure path. Always `200 {"ok":true}`.

---

### 1.8 `GET /api/results`

Paged history across every slot, newest-first as `result_store` holds it.
**Chunked.**

| Query | Default | Range |
|---|---|---|
| `offset` | 0 | any `uint32` |
| `limit` | 10 | **clamped to 10**; 0 or > 10 also becomes 10 |

```json
{
  "total": 47,
  "offset": 0,
  "results": [ {"index": 0, "result": { /* as §1.6 */ }} ]
}
```

The array stops early when `result_store_history_at()` runs out, so a page
past the end returns `results: []` with `total` still correct. Status: `200`.

> Query parsing is best-effort. The whole query string must fit in 95 bytes
> and each value in 15, or `query_u32()` **silently returns the default**
> (`web_api.c:193-204`). Values are parsed with `strtoul`, so `limit=abc`
> reads as 0 and becomes 10.

---

### 1.9 `GET /api/catalog`

Every chemistry and cell model the firmware knows. **Chunked.** No query
parameters. Status: `200`.

```json
{
  "chemistries": [
    {"name":"NMC","nominal_v":3.70,"charge_v_max":4.200,
     "discharge_v_min":2.500,"storage_v":3.700,"default_charge_c":0.50,
     "default_discharge_c":1.00,"charge_term_c":0.050,"temp_min_c":0.0,
     "temp_max_c":45.0,"rest_tolerance_pct":1.0,"rest_minutes":30}
  ],
  "models": [
    {"name":"30Q","manufacturer":"Samsung","chemistry":"NMC",
     "capacity_mah":3000,"charge_current_max_a":4.00,
     "discharge_current_max_a":15.00}
  ]
}
```

This build ships 5 chemistries (LCO, LTO, LFP, NMC, NCA) and 9 models
(Samsung 20Q/25R/30Q/30R, Sony VTC3/VTC4/VTC5/VTC5A/VTC6).

---

### 1.10 `POST /api/chemistry/<name>`

Overrides a chemistry profile and persists it to NVS. `<name>` is matched
case-insensitively against the chemistry names above.

Every field optional; what is not supplied keeps its current value, so a
client can nudge one cutoff without restating the envelope.

`nominal_v`, `charge_v_max`, `discharge_v_min`, `storage_v`,
`default_charge_c`, `default_discharge_c`, `charge_term_c`, `temp_min_c`,
`temp_max_c`, `rest_tolerance_pct`, `rest_minutes`.

Sanity-checked **after** the merge; all of these must hold or the whole
request is rejected with 400 `"profile fails sanity check"`:

- `charge_v_max > discharge_v_min`
- `charge_v_max <= 5.0` (`BTS_UNIT_MAX_VOLTAGE_V`)
- `discharge_v_min >= 0.0`
- `temp_max_c > temp_min_c`
- `default_charge_c > 0.0` and `default_discharge_c > 0.0`

| Status | When |
|---|---|
| `200` | `{"ok":true}` |
| `400` | Missing body, or the sanity check failed |
| `404` | Missing or unknown chemistry name |
| `500` | NVS write failed, or the chemistry has no profile |

> The name is taken with `strrchr(uri, '/')` — the **last** path segment, not
> a wildcard capture. `/api/chemistry/foo/NMC` resolves to `NMC`.

---

### 1.11 `POST /api/wifi`

```json
{"ssid": "bench-net", "password": "..."}
```

`password` is optional (omit for an open network); `ssid` is required.
**An empty `ssid` forgets the saved network** — erases it from NVS and stops
the station looking for it — and the AP carries on. Limits: SSID 32 chars,
password 8–64 or empty. Stored in the default NVS
partition under the `wifi` namespace, then the station reconnects. Over-long
values are **refused, not truncated** — a truncated SSID would be saved and
then never join.

| Status | When |
|---|---|
| `200` | `{"ok":true}` — saved and the join started, or forgotten |
| `400` | Missing body or `ssid` key; SSID over 32 or password over 64; password 1–7 characters |
| `500` | NVS save or erase failed |
| `503` | Saved (or forgotten), but the radio would not take the new config; it applies from the next restart |

After five failed joins the station retries every 30 s, or every 5 minutes
while a client is on the SoftAP, so the setup page stays reachable while a
wrong password is corrected — see the ESP32 README for the measurements.

#### 1.11.1 `GET /api/wifi`

```json
{"ssid":"bench-net","connected":true,"ip":"192.168.1.50",
 "ap_active":true,"ap_ssid":"BTS-Tester","ap_ip":"192.168.4.1","rssi":-61}
```

`ssid` is the live station config, `""` when none is set. `ip` is `""` and
`rssi` 0 while not joined. **There is no password field and never will be:**
the SoftAP is open, so anything returned here is readable by anyone in range.

#### 1.11.2 Firmware update — `/api/ota`

`GET /api/ota`:

```json
{"version":"7d8f53e-dirty","date":"Oct  8 2026","time":"18:52:41","idf_version":"v6.1",
 "elf_sha":"90fe12cd5","running":"ota_0","next":"ota_1","pending_verify":false,
 "confirmed":true,"rollback_possible":true,"key_set":true,"in_progress":false,
 "uptime_s":742}
```

`elf_sha` is the start of the running image's ELF SHA-256. `version` comes from
`git describe` and the date from the compile, so two builds of one dirty tree
can carry identical versions; the hash is what proves an update changed the
code.

`pending_verify` is true while a newly written image is on trial: it confirms
itself once the BTS link answers a poll, or after 180 s regardless, and a
reboot before then rolls it back.

`POST /api/ota/key` — `{"current":"...","key":"..."}`. `current` is ignored
when no key is stored (trust on first use) and must match otherwise. An empty
`key` clears it, which disables updates.

| Status | When |
|---|---|
| `200` | Set, changed or cleared |
| `400` | Missing `key`, or over 64 characters — refused, not truncated |
| `403` | `current` does not match the stored key |

`POST /api/ota` — the body is the **raw** `bts_btle_proxy.bin`, not multipart;
curl needs `--data-binary`. The key goes in the `X-OTA-Key` header. On success
the response is sent and the proxy restarts 1.5 s later.

| Status | When |
|---|---|
| `200` | Written, verified, boot slot switched; restarting |
| `400` | Empty body; wrong chip, wrong project or not an app image (checked from the first 288 bytes); hash failure; upload interrupted |
| `403` | No key set yet, or `X-OTA-Key` missing or wrong |
| `409` | A slot is running and `?force=1` was not given — the restart would stop it; or another upload is in progress |
| `413` | Larger than the app partition (1.875 MB) |
| `500` | Flash write failed |

> **The key is not a security boundary.** It is set through the same
> unauthenticated API, so it protects a unit provisioned before an attacker
> reached it, not one provisioned after. It is there to stop an accident.

---

### 1.12 `GET /api/registers`

Raw register block read. For bring-up and for verifying block strides against
a live unit; **not part of the control surface**.

| Query | Default | Behaviour |
|---|---|---|
| `addr` | 0 | Byte address. Must be a multiple of 4, else 400 |
| `count` | 8 | Registers to read. 0 or > 32 → **clamped to 32**, not an error |

```json
{"addr":592,"count":12,"ok":true,
 "values":[1.0000,0.0000,1.0000,0.0000,0.1002,0.0013,9.9800,-0.0130,
           0.2029,0.0011,4.9285,-0.0054]}
```

| Status | When |
|---|---|
| `200`, `ok: true` | Values present |
| `200`, `ok: false` | **The I2C read failed.** `error` holds the `esp_err_t` name; no `values` array |
| `400` | `addr` is not a multiple of 4 |

> **Two traps here.**
>
> 1. **A failed read returns HTTP 200.** A client that checks only the status
>    code will treat a dead I2C bus as a successful empty response. Check the
>    `ok` key.
> 2. **`addr` is not range-checked.** It is cast to `uint16_t` and sent as-is
>    (`web_api.c:740`), unlike the POST below, which does bound it. An
>    address past the top of the map returns `-1.0000` for every register —
>    that is the target's own out-of-range sentinel (`com_cpu2.c:2527`), not
>    a real reading. A burst that runs off the end repeats the last register
>    rather than wrapping (§2.4).

The read is a **single I2C transaction** regardless of `count`, using the
target's auto-increment.

---

### 1.13 `POST /api/registers`

Generic register write, the mirror of the read above.

```json
{"addr": 1016, "value": 0.84968}
```

Both keys are required.

| Status | When |
|---|---|
| `200` | `{"ok":true}` |
| `400` | Missing body, missing `addr` or `value`, `addr` out of range, or `addr % 4 != 0` |
| `502` | The I2C write failed; the message is the `esp_err_t` name |

Range is `0` to `(BTS_TOTAL_REGISTERS - 1) * 4` inclusive. The ESP32's
`BTS_TOTAL_REGISTERS` is **280**, giving a ceiling of **1116** — the top of
the slot tuning block, which is the unit's own top address. The whole map is
reachable through this endpoint, including the tuning registers above the unit
block; the one-register shortfall described in earlier revisions of §2.11 is
fixed.

> **Deliberately unguarded beyond the address checks.** This is the escape
> hatch for bring-up and for anything the typed endpoints do not cover
> (`web_api.c:762-768`). The unit enforces its own RW access list per
> register — but it does so **silently**: a write to a read-only register is
> dropped by the target with no NAK and no error, so this endpoint returns
> `{"ok":true}` for a write that did nothing (§2.5).
>
> There is also no readback. A `200` means the bytes reached the bus, not
> that the register changed.
>
> Driving calibration through this endpoint bypasses the argument
> sanitisation the typed endpoints apply. In particular
> `bts_link_cal_capture_current()` takes `fabsf()` of the measured amps
> (`bts_link.c:330`); writing a signed value straight into `eCalArgument`
> (1016) does not get that, and a negative current capture inverts the slot's
> stored gain in a way that passes validation and looks plausible
> afterwards.

---

### 1.14 `GET /api/i2c_diag`

Bus-level diagnostic, for bring-up. Separates the two failure modes that both
surface as a bare `ESP_ERR_TIMEOUT` through `/api/registers`.

```json
{"sda_high":true,"scl_high":true,"expected_addr":80,"targets_found":1,
 "addresses":[80],"verdict":"bus healthy"}
```

| Key | Meaning |
|---|---|
| `sda_high` / `scl_high` | The line read as a plain input. Both must idle high |
| `expected_addr` | 80 decimal = `0x50` |
| `targets_found` | Devices that answered a probe across `0x08`–`0x77` |
| `addresses` | Up to 16 responding addresses, **decimal** |
| `verdict` | One of the three strings below |

| Verdict | Meaning |
|---|---|
| `"a bus line is stuck low - check pull-ups and wiring"` | No transfer can work until this is fixed. The scan is skipped — probing a stuck bus produces 128 timeouts and takes half a minute |
| `"bus idle but no target answered - check address, power, or whether SDA and SCL are swapped"` | Wiring is sane, nothing is answering |
| `"bus healthy"` | At least one target responded |

Status: `200`. A full scan takes a few seconds and holds the bus mutex, so
the poll task stalls for the duration.

---

### 1.15 `GET /api/calibration`

Full calibration state: the live telemetry window, the capture flags broken
out, the persisted-validity ticks, and the selected slot's stored gains.

```json
{
  "calibration": {
    "active": true,
    "slot": 2,
    "status": 7,
    "result": 0,
    "result_text": "ok",
    "captures": {
      "voltage_low": true, "voltage_high": true,
      "current_zero": false, "current_loaded": false,
      "voltage_computed": false, "current_computed": false,
      "saved": false, "driving": false, "failed": false
    },
    "live": {
      "ads_v_pu": 0.86312, "ads_i_pu": 0.00004,
      "ads_v_v": 4.24991, "ads_i_a": 0.0004,
      "f28_v_pu": 1.70021, "f28_i_pu": 0.00011,
      "f28_v_v": 4.24973, "f28_i_a": 0.0005,
      "temp_c": 23.4
    },
    "ticks": {"voltage_valid": false, "current_valid": false}
  },
  "gains": {
    "f28v_gain": 1.000000, "f28v_offset": 0.000000,
    "f28i_gain": 1.000000, "f28i_offset": 0.000000,
    "iout_gain_pu": 0.100200, "iout_offset_pu": 0.001300,
    "iout_gain_a": 9.980040, "iout_offset_a": -0.012974,
    "vout_gain_pu": 0.202900, "vout_offset_pu": 0.001100,
    "vout_gain_v": 4.928536, "vout_offset_v": -0.005421
  }
}
```

| Key | Meaning |
|---|---|
| `active` | `eCalStatus` bit 0 |
| `slot` | Slot under calibration; **255 when none** |
| `status` | The raw `eCalStatus` bitfield, §1.16.2 |
| `result` / `result_text` | `eCalResult` of the last command and its text, §1.16.3 |
| `captures.*` | The status bits broken out, so a client need not carry its own copy of the numbering |
| `live.*` | Registers 1032–1064. `_pu` is the raw **pre-gain** reading; `_v`/`_a` are post-gain. 5 dp on the pu values, 4 dp on the engineering values, 1 dp on the temperature |
| `ticks.*` | Slot status bits 13/14 — the **persisted** validity, so a slot calibrated last month still shows its ticks |
| `gains` | The selected slot's 12-register calibration block, read live from **408 + slot×72** (`BTS_CAL_ADDR(ch, 0)`). **Omitted** when `slot` is 255 or the read fails |

Status: `200` always. `live.*` holds its last values when calibration is not
active — `active` is what tells them apart.

> **Freshness.** The `bts_link` poll task reads the 1008–1064 window as one
> burst, but **only** while calibration is active or a command has just been
> issued (`bts_link.c:504-519`). The cycle is 250 ms. Reading this endpoint
> immediately after a POST can return the pre-command state; allow one poll
> interval.

---

### 1.16 `POST /api/calibration/<action>`

Eight actions, all of which map one-to-one onto the opcodes in
[`calibration-design.md`](calibration-design.md) §5.

| URI | Opcode | Body | Argument |
|---|---|---|---|
| `/api/calibration/enter` | 1 `ENTER` | `{"slot": 0-7}` | required |
| `/api/calibration/exit` | 2 `EXIT` | none | — |
| `/api/calibration/voltage` | 3 `CAPTURE_VOLTAGE` | `{"measured_v": <float>}` | required |
| `/api/calibration/zero_current` | 4 `ZERO_CURRENT` | none | — |
| `/api/calibration/fixed_current` | 5 `SET_FIXED_CURRENT` | `{"pu": 0.0-0.8}` | required |
| `/api/calibration/current` | 6 `CAPTURE_CURRENT` | `{"measured_a": <float>}` | required, **magnitude** |
| `/api/calibration/save` | 7 `COMPUTE_SAVE` | none | — |
| `/api/calibration/clear` | 8 `CLEAR` | none | — |

The four no-argument actions ignore the body entirely; send `{}` or nothing.

Every action returns `{"ok":true}` on success and the mapping below on
failure (`send_cal_result()`, `web_api.c:886-898`):

| Status | When |
|---|---|
| `200` | Accepted, `eCalResult == 0` |
| `400` | Missing or unparseable argument; `slot` outside 0–7; `pu` outside 0.0–0.8 (`ESP_ERR_INVALID_ARG` → `"argument out of range"`) |
| `404` | Missing or unknown action segment |
| `409` | **The unit refused.** The message is the `eCalResult` text |
| `502` | I2C transport failure; the message is the `esp_err_t` name |

> **409 is the interesting one.** It means the command reached the BTS and
> the BTS said no. The nine reasons are in §1.16.3 and each has a specific
> remedy in [`README.md`](README.md)'s troubleshooting table. Do not retry a
> 409 — a refusal will be refused again.

`measured_a` is passed through `fabsf()` before it reaches the wire. The
firmware applies the discharge sign itself; entering a signed value is the
single easiest way to invert a slot's current reading permanently.

`pu` is checked twice: the ESP32 rejects `< 0.0` or `> 0.8` before anything
goes on the bus (`bts_link.c:320-322`), and the unit clamps again. 1.0 pu ≈
10 A, so 0.8 is about 8 A.

#### 1.16.1 The three-write sequence

Each action is **three I2C transactions under one take of the bus mutex**
(`cal_command()`, `bts_link.c:242-277`):

1. write `eCalArgument` (1016)
2. write `eCalCommand` (1012)
3. read `eCalResult` (1024)

They cannot be interleaved with the poll task or another caller, because the
opcode is **consumed on write and self-clears** — an argument that arrived
afterwards would be applied to nothing. `enter` writes `eCalSlot` (1008)
first, as a fourth transaction outside that group.

#### 1.16.2 `status` bitfield (`eCalStatus`)

| Bit | Mask | `captures` key | Meaning |
|---|---|---|---|
| 0 | `0x001` | (`active`) | Calibration active |
| 1 | `0x002` | `voltage_low` | Voltage low point captured |
| 2 | `0x004` | `voltage_high` | Voltage high point captured |
| 3 | `0x008` | `current_zero` | Current zero point captured |
| 4 | `0x010` | `current_loaded` | Current loaded point captured |
| 5 | `0x020` | `voltage_computed` | Voltage calibration computed and valid |
| 6 | `0x040` | `current_computed` | Current calibration computed and valid |
| 7 | `0x080` | `saved` | Written to F-RAM |
| 8 | `0x100` | `driving` | Fixed-current mode currently driving |
| 9 | `0x200` | `failed` | Last command failed — read `result` |

Bit 7 is owned by CPU2, which performs the F-RAM write from its idle loop and
never from an ISR, and is OR-ed back over whatever CPU1 published
(`com_cpu2.c:2046-2048`). Any new command clears it
(`com_cpu2.c:2180-2183`), so bit 7 always refers to the most recent `save`.

#### 1.16.3 `result` codes (`eCalResult`)

| Code | `result_text` | Meaning |
|---|---|---|
| 0 | `ok` | Accepted |
| 1 | `another slot is calibrating` | One slot at a time |
| 2 | `slot is running a test` | Stop it — `POST /api/abort_all` |
| 3 | `slot disabled or not a group leader` | ENABLE strap masks it off, or it follows a lower-numbered leader |
| 4 | `pu outside the required window` | The reading is between 0.2 and 0.8; the firmware cannot tell which point you meant |
| 5 | `insufficient captures` | Voltage needs both points; current needs the zero plus one loaded point |
| 6 | `computed gain failed validation` | Almost always a wiring error |
| 7 | `F-RAM write failed` | Check the I2C bus: `GET /api/i2c_diag` |
| 8 | `argument out of range` | |
| 9 | `not in the calibration state` | Issue `enter` first |
| other | `unknown` | |

---

## 2 (Part 1). Route ordering — do not "tidy" this

`esp_http_server` is configured with
`cfg.uri_match_fn = httpd_uri_match_wildcard`, and that matcher **honours
only a TRAILING asterisk**. A pattern with the wildcard anywhere else does
not match the way it reads: the matcher compares the literal prefix up to the
asterisk and then accepts any tail.

Two consequences shape the whole route table.

### The first matching pattern wins

`httpd_register_uri_handler()` appends, and dispatch takes the **first
registered pattern that matches**. So every exact path must be registered
**before** any wildcard that would also match it.

In `s_routes[]` (`web_api.c`) that ordering is:

```
/                      GET     exact     the setup page
/index.html            GET     exact
/api/status            GET     exact
/api/catalog           GET     exact
/api/results           GET     exact
/api/registers         GET     exact
/api/registers         POST    exact
/api/calibration       GET     exact     <-- BEFORE /api/calibration/*
/api/i2c_diag          GET     exact
/api/abort_all         POST    exact
/api/wifi              GET     exact
/api/wifi              POST    exact
/api/ota               GET     exact
/api/ota               POST    exact
/api/ota/key           POST    exact
/api/chemistry/*       POST    wildcard
/api/calibration/*     POST    wildcard
/api/slot/*            POST    wildcard
/api/slot/*            GET     wildcard
/*                     OPTIONS wildcard  <-- last
```

Move `GET /api/calibration` below `POST /api/calibration/*` and the exact
path still works only because the methods differ. Move `/*` anywhere but
last and it would swallow every OPTIONS request that a more specific pattern
should have handled. **Neither of these is a style choice.**

### Per-action dispatch is manual, and has to be

A pattern like `/api/slot/*/config` **never matches**, because the asterisk
is not trailing — the matcher takes `/api/slot/` as the literal prefix and
accepts anything after it. Registering the per-action patterns individually
therefore does not work: they all collapse onto the `/api/slot/` prefix and
whichever was registered first wins every request.

> **This is not hypothetical.** It is what made a config POST return 405: the
> GET pattern matched it first (`web_api.c:1057-1072`).

So **one pattern is registered per method** and the trailing segment is
dispatched in C:

| Dispatcher | Registered pattern | Picks on |
|---|---|---|
| `h_slot_get_dispatch` | `GET /api/slot/*` | `strstr(uri, "/result")` → result, else the slot object |
| `h_slot_post_dispatch` | `POST /api/slot/*` | `strstr` for `/config` and `/serial`, then the **exact** trailing segment for `start`\|`abort`\|`clear`\|`pause`\|`resume` |
| `h_cal_post_dispatch` | `POST /api/calibration/*` | `strcmp` on the **last** segment, via `strrchr(uri, '/')` |

The slot number is parsed out of the URI by each handler itself
(`slot_from_uri()`, `web_api.c:178-190`), which looks for `/slot/` and
`atoi`s what follows, returning −1 for anything missing or ≥ 8. So every
handler has one check rather than trusting a wildcard match.

Note the dispatchers differ in strictness. The calibration one and the slot
**action** one both `strcmp` the final segment and so are **exact**; only the
`/config` and `/serial` tests ahead of the actions are still substring
matches. The action tests were converted to exact matching when pause and
resume arrived — see §1.7.

**If you refactor this file:** keep the exact paths above the wildcards, keep
`/*` last, and do not replace the manual dispatch with mid-path wildcards.
They will compile, register without error, and route everything to the wrong
handler.

---

## 3 (Part 1). CORS

The tester is a LAN appliance and its web UI is served from elsewhere — a
local file, or a dev server — so a browser reaching it cross-origin is the
normal case rather than the exception (`web_api.c:50-55`).

| Response path | `Access-Control-Allow-Origin: *` |
|---|---|
| `send_json()` success | yes |
| `send_json()` 500 "response too large" | **no** — see §1.2 |
| `chunk_begin()` (status, results, catalog) | yes, set before the first chunk |
| `send_error()` — every 4xx and 5xx it raises | yes |
| `h_options()` preflight | yes |

Preflight, `OPTIONS /*` → `204 No Content` with:

```
Access-Control-Allow-Origin: *
Access-Control-Allow-Methods: GET, POST, OPTIONS
Access-Control-Allow-Headers: Content-Type
```

There is no `Access-Control-Max-Age`, so browsers apply their own default and
will re-preflight regularly. Credentials are not allowed (`*` cannot be
combined with `Access-Control-Allow-Credentials`), which is moot — there is
no authentication.

---
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

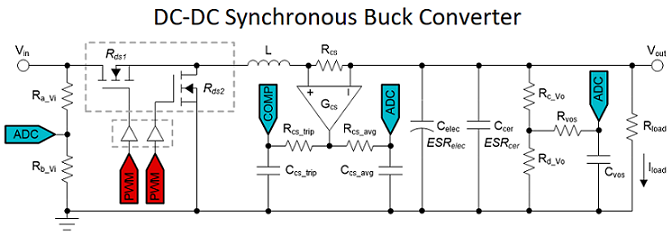
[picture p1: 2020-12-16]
Hardware/source/tida-010086/bts_F2837xD_8ch/devkits/TIDM_DC_DC_BTS/bts/F28004x/KitPowerStage.png

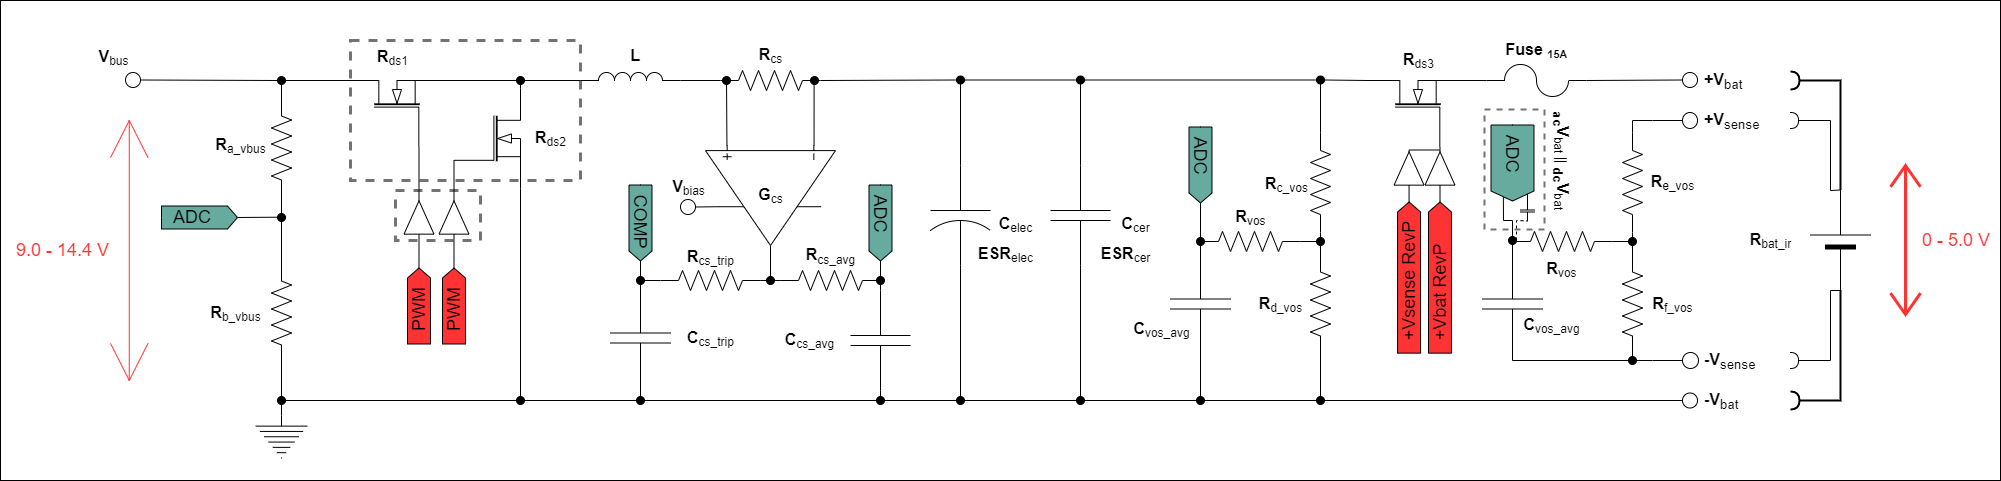
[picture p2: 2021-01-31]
Hardware/schematics/TIDA-010086/tida-010086.png

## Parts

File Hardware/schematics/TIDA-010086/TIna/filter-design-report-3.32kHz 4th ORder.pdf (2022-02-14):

## Filter Design Report

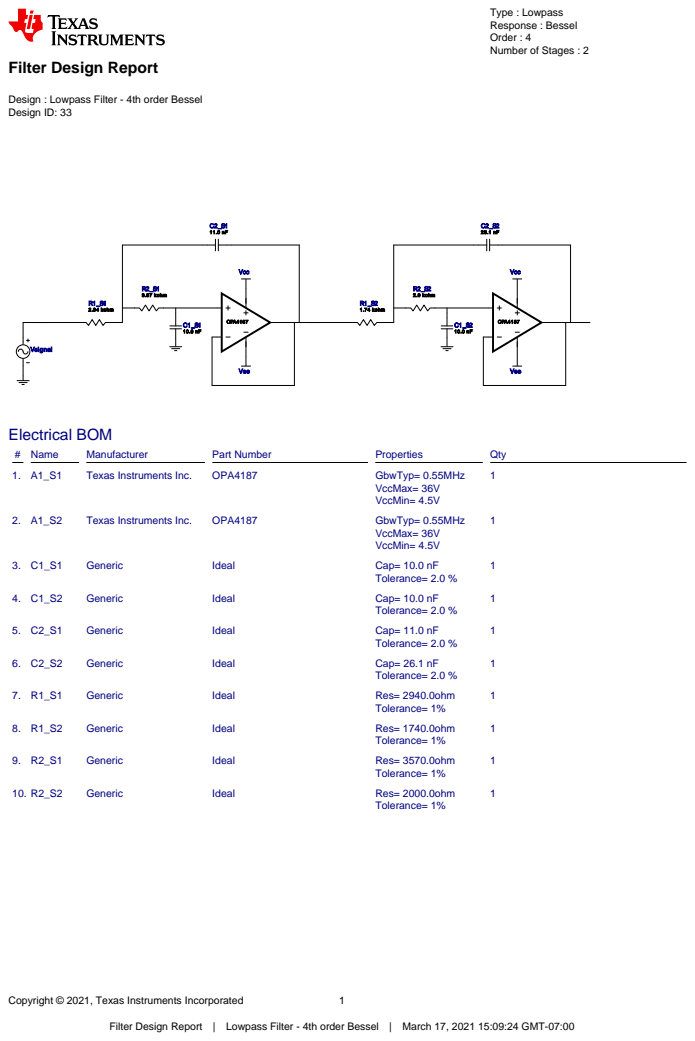
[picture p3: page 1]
Copyright © 2021, Texas Instruments Incorporated; Vsignal; OPA4187 C1_S1; R1_S1 2.94 kohm; R2_S1 3.57 kohm; Vcc; Vee; OPA4187 C1_S2; R1_S2 1.74 kohm; R2_S2 2.0 kohm; Electrical BOM; # Name; Manufacturer; Part Number; Properties; Qty; Texas Instruments Inc.; OPA4187; GbwTyp= 0.55MHz; VccMax= 36V VccMin= 4.5V; Generic; Ideal; Cap= 10.0 nF; Tolerance= 2.0 %; Cap= 11.0 nF; Cap= 26.1 nF; Res= 2940.0ohm; Tolerance= 1%; Res= 1740.0ohm; Res= 3570.0ohm; Res= 2000.0ohm

Type : Lowpass
Response : Bessel
Order : 4
Number of Stages : 2

Design : Lowpass Filter - 4th order Bessel
Design ID: 33

Filter Design Report | Lowpass Filter - 4th order Bessel | March 17, 2021 15:09:24 GMT-07:00

## Sensitivity Analysis

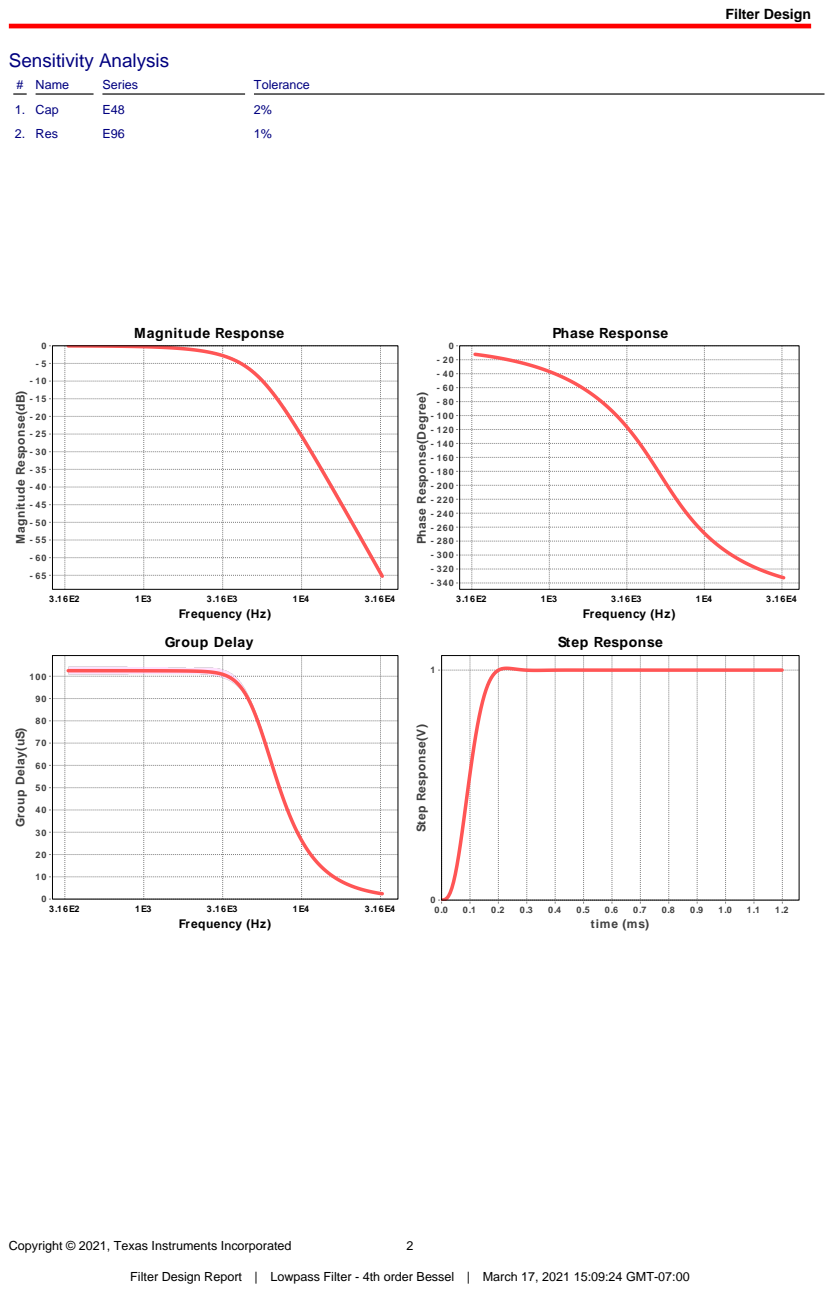
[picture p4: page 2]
Filter Design; # Name; Series; Tolerance; 1. Cap; 2. Res; Magnitude Response; 3.16E4 Frequency (Hz); Phase Response; Group Delay; Step Response; time (ms); 1Step Response⁽V⁾

Magnitude Response(dB)

Phase Response(Degree)

Group Delay(uS)

## Design Inputs

# | Name | Value | Description

1. FilterType | lowpass
2. FilterResponse | Bessel
3. FilterOrder | 4.0
4. FilterTopology | Sallen-Key
5. NumberOfStages | 2.0
6. PassbandFrequency | 3.32 k
7. StopbandAttenuation | -65.946
8. StopbandFrequency | 33.2 k
9. Gain | 1.0
10. DualSupply | +/-5.00 V | Power supply(s) to active chips
11. ResistorTolerance | E96 | Resistor series - 1% Passive resistor tolerance
12. CapacitorTolerance | E48 | Capacitor series - 2% Passive capacitor tolerance

## Design Assistance

1. OPA4187 Product Folder : http://www.ti.com/product/OPA4187 : contains the data sheet and other resources.

# Filter Stage :1

Cutoff Frequency | 4.684 kHz
Min GBW Reqd | 245.928 kHz
Stage Gain | 1.0 V/V
Stage Q | 521.943 m
Stage Topology | Sallen-Key

OPA4187 C1_S1
10.0 nF

C2_S1
11.0 nF

R1_S1
2.94 kohm

R2_S1
3.57 kohm

Vcc

Vee

## Electrical BOM

# Name | Manufacturer | Part Number | Properties | Qty

1. A1_S1 | Texas Instruments Inc. | OPA4187 | GbwTyp= 0.55MHz VccMax= 36V VccMin= 4.5V | 1
2. C1_S1 | Generic | Ideal | Cap= 10.0 nF Tolerance= 2.0 %

1

3. C2_S1 | Generic | Ideal | Cap= 11.0 nF Tolerance= 2.0 %

1

4. R1_S1 | Generic | Ideal | Res= 2940.0ohm Tolerance= 1%

1

5. R2_S1 | Generic | Ideal | Res= 3570.0ohm Tolerance= 1%

1

# Filter Stage :2

Cutoff Frequency | 5.281 kHz
Min GBW Reqd | 425.556 kHz
Stage Gain | 1.0 V/V
Stage Q | 805.82 m
Stage Topology | Sallen-Key

OPA4187 C1_S2
10.0 nF

C2_S2
26.1 nF

R1_S2
1.74 kohm

R2_S2
2.0 kohm

Vcc

Vee

## Electrical BOM

# Name | Manufacturer | Part Number | Properties | Qty

1. A1_S2 | Texas Instruments Inc. | OPA4187 | GbwTyp= 0.55MHz VccMax= 36V VccMin= 4.5V | 1
2. C1_S2 | Generic | Ideal | Cap= 10.0 nF Tolerance= 2.0 %

1

3. C2_S2 | Generic | Ideal | Cap= 26.1 nF Tolerance= 2.0 %

1

4. R1_S2 | Generic | Ideal | Res= 1740.0ohm Tolerance= 1%

1

5. R2_S2 | Generic | Ideal | Res= 2000.0ohm Tolerance= 1%

1

Important Notice and Disclaimer

TI provides technical and reliability data (including datasheets), design resources (including reference designs), application or other design advice, web tools, safety information, and other resources AS IS and with all faults, and disclaims all warranties. These resources are intended for skilled developers designing with TI products. You are solely responsible for (1) selecting the appropriate TI products for your application, (2) designing, validating and testing your application, and (3) ensuring your application meets applicable standards, and any other safety, security, or other requirements.

These resources are subject to change without notice. TI grants you permission to use these resources only for development of an application that uses the TI products described in the resource. Other reproduction and display of these resources is prohibited. No license is granted to any other TI intellectual property right or to any third party intellectual property right. TI disclaims responsibility for, and you will fully indemnify TI and its representatives against, any claims, damages, costs, losses, and liabilities arising out of your use of these resources.

Providing these resources does not expand or otherwise alter TI's applicable Terms of Sale or other applicable terms available either on ti.com or provided in conjunction with TI products.

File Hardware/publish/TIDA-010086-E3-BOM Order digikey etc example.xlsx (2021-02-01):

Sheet: Manufacturing
 |  | Bill of Materials for |  | TIDA-010086_mod.PrjPcb
 |  | Source Data From: |  | XTIDA-010086.BomDoc
 |  | Variant: |  | 001
 |  | Report Date: |  | 5/01/2021 5:48 AM
 |  |  |  | Primary |  |  |  |  |  |  | DigiKey Format
ItemRef | Designator | Description | Qty | Supplier | SPU | Manufacturer | MPN | Column1 | Line# | Ref# | Qty, | SPN, | Des,
T10086-1 | R216_Ch1, R216_Ch2, R216_Ch3, R216_Ch4, R216_Ch5, R216_Ch6, R216_Ch7, R216_Ch8 | RES SMD 1K OHM 0.1% 1/10W 0603 | 8 | Digi-Key | ‎YAG2314CT-ND‎ | Yageo | RT0603BRE071KL |  | 1 | T10086-1 | 8 | ‎YAG2314CT-ND‎ | T10086-1
T10086-2 | R217_Ch1, R217_Ch2, R217_Ch3, R217_Ch4, R217_Ch5, R217_Ch6, R217_Ch7, R217_Ch8 | RES SMD 560 OHM 0.1% 1/10W 0603 | 8 | Digi-Key | YAG1689CT-ND | Yageo | RT0603BRD07560RL |  | 2 | T10086-2 | 0 | YAG1689CT-ND | T10086-2
T10086-3 | J5 | 0.8MM HIGH SPEED ASSEMBLY. | 1 | Digi-Key | SAM13312-ND | Samtec | HSEC8-160-01-L-RA-BL |  | 3 | T10086-3 | 1 | SAM13312-ND | T10086-3
T10086-4 | R243 | RES 120 OHM 5% 1/2W 1210 | 1 | Digi-Key | ‎RMCF1210JT120RCT-ND‎ | Yageo | RC1210JR-07120RL |  | 4 | T10086-4 | 1 | ‎RMCF1210JT120RCT-ND‎ | T10086-4
T10086-5 | U20 | 250-mA Ultra-Low-Noise, Low-IQ LDO, DBV0005A (SOT-23-5) | 1 | TI store | LP5907MFX-3.3/NOPB | Texas Instruments | LP5907MFX-3.3/NOPB |  | 5 | T10086-5 | 0 | LP5907MFX-3.3/NOPB | T10086-5
T10086-6 | U35 | 3.3V CAN Transceiver with Sleep Mode, 6 mA, -40 to 125 degC, 8-pin SOIC (D), Green (RoHS & no Sb/Br) | 1 | TI store | SN65HVD234DR | Texas Instruments | SN65HVD234DR |  | 6 | T10086-6 | 0 | SN65HVD234DR | T10086-6
T10086-7 | C3_Ch1, C3_Ch2, C3_Ch3, C3_Ch4, C3_Ch5, C3_Ch6, C3_Ch7, C3_Ch8 | 330µF 35V Aluminum Polymer Capacitor Radial, Can - SMD 18mOhm 1000 Hrs @ 125°C | 8 | LCSC | C178373 | Panasonic | 35SVPK330M |  | 7 | T10086-7 | 8 | C178373 | T10086-7
T10086-8 | U2_Ch1, U2_Ch2, U2_Ch3, U2_Ch4, U2_Ch5, U2_Ch6, U2_Ch7, U2_Ch8, U5_Ch1, U5_Ch2, U5_Ch3, U5_Ch4, U5_Ch5, U5_Ch6, U5_Ch7, U5_Ch8, U6_Ch1, U6_Ch2, U6_Ch3, U6_Ch4, U6_Ch5, U6_Ch6, U6_Ch7, U6_Ch8 | 36V, Low Power, RRO, General Purpose Operational Amplifier, D0008A (SOIC-8) | 24 | Digi-Key | 296-TLV2171IDRCT-ND | Texas Instruments | TLV2171IDR |  | 8 | T10086-8 | 22 | 296-TLV2171IDRCT-ND | T10086-8
T10086-9 | U10_Ch1, U10_Ch2, U10_Ch3, U10_Ch4, U10_Ch5, U10_Ch6, U10_Ch7, U10_Ch8, U14 | 36V, Low-Power, RRO, General-Purpose Operational Amplifier, DBV0005A (SOT-23-5) | 9 | Digi-Key | 296-47216-1-ND | Texas Instruments | TLV171IDBVR |  | 9 | T10086-9 | 8 | 296-47216-1-ND | T10086-9
T10086-10 | U7, U9 | 4-Channel Single ADC Delta-Sigma 1ksps 16-bit Serial 16-Pin TSSOP T/R | 2 | TI store | ADS1119IPWR | Texas Instruments | ADS1119IPWR |  | 10 | T10086-10 | 0 | ADS1119IPWR | T10086-10
T10086-11 | U22, U31 | 500mA Low Dropout CMOS Linear Regulators Stable with Ceramic Output Capacitors, 5-pin SOT-223, Pb-Free, 1000 Reel | 2 | TI store | LP38693MP-5.0/NOPB | Texas Instruments | LP38693MP-5.0/NOPB |  | 11 | T10086-11 | 0 | LP38693MP-5.0/NOPB | T10086-11
T10086-12 | C9_Ch1, C9_Ch2, C9_Ch3, C9_Ch4, C9_Ch5, C9_Ch6, C9_Ch7, C9_Ch8, C10_Ch1, C10_Ch2, C10_Ch3, C10_Ch4, C10_Ch5, C10_Ch6, C10_Ch7, C10_Ch8 | 560µF 20V Aluminum Polymer Capacitor Radial, Can - SMD 12mOhm 1000 Hrs @ 125°C | 16 | Digi-Key | ‎P122119CT-ND‎ | Panasonic | 20SVF560M |  | 12 | T10086-12 | 16 | ‎P122119CT-ND‎ | T10086-12
T10086-13 | U12, U16 | 8-Channel, 24-Bit, Simultaneously-Sampling, Delta-Sigma ADC, PBS0032A (TQFP-32) | 2 | TI store | ADS131M08IPBSR | Texas Instruments | ADS131M08IPBSR |  | 13 | T10086-13 | 0 | ADS131M08IPBSR | T10086-13
T10086-14 | U15, U19 | 8ppm/°C Drift, Low-Power, Dual-Output Vref and Vref/2 Voltage Reference 5-SOT-23-THIN -40 to 125 | 2 | TI store | REF2025AIDDCR | Texas Instruments | REF2025AIDDCR |  | 14 | T10086-14 | 0 | REF2025AIDDCR | T10086-14
T10086-15 | C109 | CAP, AL, 22 µF, 100 V, +/- 20%, 0.55 ohm, SMD | 1 | Element14 | 1698521 | United Chemi-Con | EMVH101ADA220MJA0G |  | 15 | T10086-15 | 1 | 1698521 | T10086-15
T10086-16 | C113 | CAP, Aluminum Polymer, 180 µF, 16 V, +/- 20%, 0.016 ohm, HC0 SMD | 1 | Digi-Key | 565-3078-1-ND | United Chemi-Con | APXA160ARA181MHC0G |  | 16 | T10086-16 | 1 | 565-3078-1-ND | T10086-16
T10086-17 | C165 | CAP, CERM, 0.01 µF, 100 V, +/- 10%, X7R, 0603 | 1 | Digi-Key | 478-1205-1-ND | Kyocera AVX | 06031C103KAT2A |  | 17 | T10086-17 | 0 | 478-1205-1-ND | T10086-17
T10086-18 | C126, C169, C184_Ch1, C184_Ch2, C184_Ch3, C184_Ch4, C184_Ch5, C184_Ch6, C184_Ch7, C184_Ch8 | CAP, CERM, 0.01 µF, 25 V,+/- 5%, C0G/NP0, AEC-Q200 Grade 1, 0603 | 10 | Digi-Key | 399-14102-1-ND | KEMET | C0603C103J3GECAUTO |  | 18 | T10086-18 | 10 | 399-14102-1-ND | T10086-18
T10086-19 | C57, C59 | CAP, CERM, 0.01 µF, 50 V, +/- 5%, C0G/NP0, 0603 | 2 | Digi-Key | 490-9666-1-ND | Murata | GRM1885C1H103JA01D |  | 19 | T10086-19 | 2 | 490-9666-1-ND | T10086-19
T10086-20 | C120 | CAP, CERM, 0.056 µF, 50 V, +/- 10%, X7R, 0603 | 1 | Digi-Key | 311-4100-1-ND | Yageo | CC0603KRX7R9BB563 |  | 20 | T10086-20 | 1 | 311-4100-1-ND | T10086-20
T10086-21 | C112, C116 | CAP, CERM, 0.1 µF, 100 V, +/- 10%, X7R, 0603 | 2 | Digi-Key | 490-3285-1-ND | Murata | GRM188R72A104KA35D |  | 21 | T10086-21 | 2 | 490-3285-1-ND | T10086-21
T10086-22 | C111, C121 | CAP, CERM, 0.1 µF, 100 V, +/- 10%, X7R, 0805 | 2 | Digi-Key | 445-1418-1-ND | TDK | C2012X7R2A104K125AA |  | 22 | T10086-22 | 2 | 445-1418-1-ND | T10086-22
T10086-23 | C1_Ch1, C1_Ch2, C1_Ch3, C1_Ch4, C1_Ch5, C1_Ch6, C1_Ch7, C1_Ch8, C30, C43, C44, C55, C56, C136, C454, C455, C460 | CAP, CERM, 0.1 µF, 25 V, +/- 5%, X7R, 0603 | 17 | Digi-Key | 399-1282-1-ND | KEMET | C0603C104J3RACTU |  | 23 | T10086-23 | 17 | 399-1282-1-ND | T10086-23
T10086-24 | C7_Ch1, C7_Ch2, C7_Ch3, C7_Ch4, C7_Ch5, C7_Ch6, C7_Ch7, C7_Ch8, C11_Ch1, C11_Ch2, C11_Ch3, C11_Ch4, C11_Ch5, C11_Ch6, C11_Ch7, C11_Ch8, C14_Ch1, C14_Ch2, C14_Ch3, C14_Ch4, C14_Ch5, C14_Ch6, C14_Ch7, C14_Ch8, C20_Ch1, C20_Ch2, C20_Ch3, C20_Ch4, C20_Ch5, C20_Ch6, C20_Ch7, C20_Ch8, C23_Ch1, C23_Ch2, C23_Ch3, C23_Ch4, C23_Ch5, C23_Ch6, C23_Ch7, C23_Ch8, C25_Ch1, C25_Ch2, C25_Ch3, C25_Ch4, C25_Ch5, C25_Ch6, C25_Ch7, C25_Ch8, C29_Ch1, C29_Ch2, C29_Ch3, C29_Ch4, C29_Ch5, C29_Ch6, C29_Ch7, C29_Ch8, C31_Ch1, C31_Ch2, C31_Ch3, C31_Ch4, C31_Ch5, C31_Ch6, C31_Ch7, C31_Ch8, C36_Ch1, C36_Ch2, C36_Ch3, C36_Ch4, C36_Ch5, C36_Ch6, C36_Ch7, C36_Ch8, C45_Ch1, C45_Ch2, C45_Ch3, C45_Ch4, C45_Ch5, C45_Ch6, C45_Ch7, C45_Ch8, C53_Ch1, C53_Ch2, C53_Ch3, C53_Ch4, C53_Ch5, C53_Ch6, C53_Ch7, C53_Ch8, C54_Ch1, C54_Ch2, C54_Ch3, C54_Ch4, C54_Ch5, C54_Ch6, C54_Ch7, C54_Ch8, C62, C70, C73, C76, C77, C80, C83, C91, C94, C97, C98, C101, C122, C123, C127-C129, C131, C134, C138, C142-C146, C166_Ch1, C166_Ch2, C166_Ch3, C166_Ch4, C166_Ch5, C166_Ch6, C166_Ch7, C166_Ch8, C167_Ch1, C167_Ch2, C167_Ch3, C167_Ch4, C167_Ch5, C167_Ch6, C167_Ch7, C167_Ch8, C174_Ch1, C174_Ch2, C174_Ch3, C174_Ch4, C174_Ch5, C174_Ch6, C174_Ch7, C174_Ch8, C176, C181_Ch1, C181_Ch2, C181_Ch3, C181_Ch4, C181_Ch5, C181_Ch6, C181_Ch7, C181_Ch8, C182_Ch1, C182_Ch2, C182_Ch3, C182_Ch4, C182_Ch5, C182_Ch6, C182_Ch7, C182_Ch8, C183_Ch1, C183_Ch2, C183_Ch3, C183_Ch4, C183_Ch5, C183_Ch6, C183_Ch7, C183_Ch8, C185_Ch1, C185_Ch2, C185_Ch3, C185_Ch4, C18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 | CAP, CERM, 0.1 uF, 25 V, +/- 5%, X7R, 0603 | 183 | Arrow Electronics | 06033C104JAT2A | Kyocera AVX | 06033C104JAT2A |  | 24 | T10086-24 | 183 | 06033C104JAT2A | T10086-24
T10086-25 | C164 | CAP, CERM, 0.22 µF, 16 V,+/- 10%, X7R, 0402 | 1 | Digi-Key | ‎445-5936-1-ND‎ | TDK Corporation | C1005X7R1C224K050BC‎ |  | 25 | T10086-25 | 1 | ‎445-5936-1-ND‎ | T10086-25
T10086-26 | C159 | CAP, CERM, 1 µF, 16 V,+/- 10%, X5R, 0402 | 1 | Digi-Key | 1276-1067-1-ND | Samsung | CL05A105KO5NNNC |  | 26 | T10086-26 | 1 | 1276-1067-1-ND | T10086-26
T10086-27 | C8_Ch1, C8_Ch2, C8_Ch3, C8_Ch4, C8_Ch5, C8_Ch6, C8_Ch7, C8_Ch8, C18_Ch1, C18_Ch2, C18_Ch3, C18_Ch4, C18_Ch5, C18_Ch6, C18_Ch7, C18_Ch8, C24_Ch1, C24_Ch2, C24_Ch3, C24_Ch4, C24_Ch5, C24_Ch6, C24_Ch7, C24_Ch8, C32, C34, C42, C52_Ch1, C52_Ch2, C52_Ch3, C52_Ch4, C52_Ch5, C52_Ch6, C52_Ch7, C52_Ch8, C58, C69, C74, C75, C78, C79, C90, C95, C96, C99, C100, C102, C103, C105, C108, C118, C119, C124, C125, C135, C140, C141, C150, C173, C175, C177_Ch1, C177_Ch2, C177_Ch3, C177_Ch4, C177_Ch5, C177_Ch6, C177_Ch7, C177_Ch8, C179_Ch1, C179_Ch2, C179_Ch3, C179_Ch4, C179_Ch5, C179_Ch6, C179_Ch7, C179_Ch8, C195, C453 | CAP, CERM, 1 uF, 25 V, +/- 10%, X7R, 0603 | 78 | Digi-Key | 1276-1184-1-ND | Samsung | CL10B105KA8NNNC |  | 27 | T10086-27 | 50 | 1276-1184-1-ND | T10086-27
T10086-28 | C41, C47, C449, C459 | CAP, CERM, 10 µF, 10 V, +/- 10%, X7T, 0603 | 4 | LCSC | C703693 | Murata | ZRB18AD71A106KE01L |  | 28 | T10086-28 | 4 | C703693 | T10086-28
T10086-29 | C110 | CAP, CERM, 10 µF, 100 V, +/- 20%, X7S, | 1 | Digi-Key | 445-5212-1-ND | TDK | C5750X7S2A106M |  | 29 | T10086-29 | 1 | 445-5212-1-ND | T10086-29
T10086-30 | C104, C106, C107 | CAP, CERM, 10 µF, 16 V, +/- 20%, X7R, 0805 | 3 | Digi-Key | 587-3319-1-ND | Taiyo Yuden | EMK212BB7106MG-T |  | 30 | T10086-30 | 3 | 587-3319-1-ND | T10086-30
T10086-31 | C139, C163 | CAP, CERM, 10 µF, 25 V,+/- 20%, X5R, 0603 | 2 | Digi-Key | 1276-1869-1-ND | Samsung | CL10A106MA8NRNC |  | 31 | T10086-31 | 2 | 1276-1869-1-ND | T10086-31
T10086-32 | C72, C93 | CAP, CERM, 10 pF, 50 V, +/- 5%, C0G/NP0, 0603 | 2 | Digi-Key | 478-1163-1-ND | Kyocera AVX | 06035A100JAT2A\4K |  | 32 | T10086-32 | 2 | 478-1163-1-ND | T10086-32
T10086-33 | C168_Ch1, C168_Ch2, C168_Ch3, C168_Ch4, C168_Ch5, C168_Ch6, C168_Ch7, C168_Ch8 | CAP, CERM, 10 pF, 50 V, +/- 5%, C0G/NP0, 0603 | 8 | Digi-Key | 490-1403-1-ND | Murata | GRM1885C1H100JA01D |  | 33 | T10086-33 | 8 | 490-1403-1-ND | T10086-33
T10086-34 | C51, C60, C61, C63, C65-C68, C71, C81, C82, C84, C86-C89, C92, C130, C132, C133, C187, C190, C192, C193 | CAP, CERM, 10 pF, 50 V,+/- 5%, C0G/NP0, AEC-Q200 Grade 1, 0402 | 24 | Digi-Key | 445-5584-1-ND | TDK | CGA2B2C0G1H100D050BA |  | 34 | T10086-34 | 24 | 445-5584-1-ND | T10086-34
T10086-35 | C137 | CAP, CERM, 10 uF, 50 V, +/- 20%, X7R, 1210 | 1 | Digi-Key | 445-14933-1-ND | TDK | C3225X7R1H106M250AC |  | 35 | T10086-35 | 1 | 445-14933-1-ND | T10086-35
T10086-36 | C15_Ch1, C15_Ch2, C15_Ch3, C15_Ch4, C15_Ch5, C15_Ch6, C15_Ch7, C15_Ch8, C19_Ch1, C19_Ch2, C19_Ch3, C19_Ch4, C19_Ch5, C19_Ch6, C19_Ch7, C19_Ch8, C180_Ch1, C180_Ch2, C180_Ch3, C180_Ch4, C180_Ch5, C180_Ch6, C180_Ch7, C180_Ch8 | CAP, CERM, 100 pF, 50 V, +/- 5%, C0G/NP0, 0603 | 24 | Digi-Key | 490-1427-1-ND | Murata | GRM1885C1H101JA01D |  | 36 | T10086-36 | 24 | 490-1427-1-ND | T10086-36
T10086-37 | C46, C461 | CAP, CERM, 100 pF, 50 V, +/- 5%, C0G/NP0, 0603 | 2 | Newark | 96K4763 | Kyocera AVX | 06035A101JAT2A/4K |  | 37 | T10086-37 | 0 | 96K4763 | T10086-37
T10086-38 | C26_Ch1, C26_Ch2, C26_Ch3, C26_Ch4, C26_Ch5, C26_Ch6, C26_Ch7, C26_Ch8, C27_Ch1, C27_Ch2, C27_Ch3, C27_Ch4, C27_Ch5, C27_Ch6, C27_Ch7, C27_Ch8 | CAP, CERM, 1000 pF, 25 V,+/- 10%, X7R, 0402 | 16 | Digi-Key | 732-7539-1-ND | Wurth Electronics | 885012205044 |  | 38 | T10086-38 | 16 | 732-7539-1-ND | T10086-38
T10086-39 | C38_Ch1, C38_Ch2, C38_Ch3, C38_Ch4, C38_Ch5, C38_Ch6, C38_Ch7, C38_Ch8, C39_Ch1, C39_Ch2, C39_Ch3, C39_Ch4, C39_Ch5, C39_Ch6, C39_Ch7, C39_Ch8, C49_Ch1, C49_Ch2, C49_Ch3, C49_Ch4, C49_Ch5, C49_Ch6, C49_Ch7, C49_Ch8, C170_Ch1, C170_Ch2, C170_Ch3, C170_Ch4, C170_Ch5, C170_Ch6, C170_Ch7, C170_Ch8 | CAP, CERM, 1000 pF, 50 V, +/- 5%, C0G/NP0, 0603 | 32 | Digi-Key | 490-1451-1-ND | Murata | GRM1885C1H102JA01D |  | 39 | T10086-39 | 32 | 490-1451-1-ND | T10086-39
T10086-40 | C33_Ch1, C33_Ch2, C33_Ch3, C33_Ch4, C33_Ch5, C33_Ch6, C33_Ch7, C33_Ch8, C48_Ch1, C48_Ch2, C48_Ch3, C48_Ch4, C48_Ch5, C48_Ch6, C48_Ch7, C48_Ch8, C147_Ch1, C147_Ch2, C147_Ch3, C147_Ch4, C147_Ch5, C147_Ch6, C147_Ch7, C147_Ch8, C151_Ch1, C151_Ch2, C151_Ch3, C151_Ch4, C151_Ch5, C151_Ch6, C151_Ch7, C151_Ch8 | CAP, CERM, 1200 pF, 50 V,+/- 10%, X7R, 0402 | 32 | Digi-Key | 490-1304-1-ND | Murata | GRM155R71H122KA01D |  | 40 | T10086-40 | 32 | 490-1304-1-ND | T10086-40
T10086-41 | C115 | CAP, CERM, 1500 pF, 100 V, +/- 5%, C0G/NP0, 0603 | 1 | Digi-Key | 490-8276-1-ND | Murata | GRM1885C2A152JA01D |  | 41 | T10086-41 | 1 | 490-8276-1-ND | T10086-41
T10086-42 | C155 | CAP, CERM, 2.2 µF, 16 V, +/- 10%, X7R, 0603 | 1 | Digi-Key | 587-5835-1-ND | Taiyo Yuden | EMK107BB7225KA-T |  | 42 | T10086-42 | 1 | 587-5835-1-ND | T10086-42
T10086-43 | C114 | CAP, CERM, 2.2 µF, 16 V, +/- 10%, X7R, 0805 | 1 | Digi-Key | 445-1420-1-ND | TDK | C2012X7R1C225K125AB |  | 43 | T10086-43 | 1 | 445-1420-1-ND | T10086-43
T10086-44 | C160-C162 | CAP, CERM, 22 µF, 10 V, +/- 20%, X7S, 0805 | 3 | Digi-Key | 445-14560-1-ND | TDK | C2012X7S1A226M125AC |  | 44 | T10086-44 | 3 | 445-14560-1-ND | T10086-44
T10086-45 | C152-C154 | CAP, CERM, 22 µF, 16 V, +/- 20%, X7R, 1206_190 | 3 | Digi-Key | 587-4319-1-ND | Taiyo Yuden | EMK316BB7226ML-T |  | 45 | T10086-45 | 3 | 587-4319-1-ND | T10086-45
T10086-46 | C4_Ch1, C4_Ch2, C4_Ch3, C4_Ch4, C4_Ch5, C4_Ch6, C4_Ch7, C4_Ch8, C5_Ch1, C5_Ch2, C5_Ch3, C5_Ch4, C5_Ch5, C5_Ch6, C5_Ch7, C5_Ch8, C6_Ch1, C6_Ch2, C6_Ch3, C6_Ch4, C6_Ch5, C6_Ch6, C6_Ch7, C6_Ch8 | CAP, CERM, 22 µF, 25 V, +/- 10%, X7R, 1210 | 24 | LCSC | C21397 | Murata | GRM32ER71E226KE15L |  | 46 | T10086-46 | 24 | C21397 | T10086-46
T10086-47 | C117 | CAP, CERM, 330 pF, 100 V, +/- 5%, C0G/NP0, 0603 | 1 | Digi-Key | 445-2309-1-ND | TDK | C1608C0G2A331J080AA |  | 47 | T10086-47 | 1 | 445-2309-1-ND | T10086-47
T10086-48 | C157, C158 | CAP, CERM, 4.7 µF, 25 V,+/- 10%, X5R, 1206 | 2 | Digi-Key | 490-3372-1-ND | Murata | GRM319R61E475KA12D |  | 48 | T10086-48 | 2 | 490-3372-1-ND | T10086-48
T10086-49 | C12_Ch1, C12_Ch2, C12_Ch3, C12_Ch4, C12_Ch5, C12_Ch6, C12_Ch7, C12_Ch8, C13_Ch1, C13_Ch2, C13_Ch3, C13_Ch4, C13_Ch5, C13_Ch6, C13_Ch7, C13_Ch8 | CAP, CERM, 47 µF, 10 V, +/- 20%, X7R, 1210 | 16 | LCSC | C415541 | Murata | GRM32ER71A476ME15L |  | 49 | T10086-49 | 16 | C415541 | T10086-49
T10086-50 | C35_Ch1, C35_Ch2, C35_Ch3, C35_Ch4, C35_Ch5, C35_Ch6, C35_Ch7, C35_Ch8, C50_Ch1, C50_Ch2, C50_Ch3, C50_Ch4, C50_Ch5, C50_Ch6, C50_Ch7, C50_Ch8, C178_Ch1, C178_Ch2, C178_Ch3, C178_Ch4, C178_Ch5, C178_Ch6, C178_Ch7, C178_Ch8 | CAP, CERM, 7500 pF, 50 V,+/- 5%, C0G/NP0, 0805 | 24 | Digi-Key | ‎490-1639-1-ND‎ | Murata | GRM2195C1H752JA01D |  | 50 | T10086-50 | 24 | ‎490-1639-1-ND‎ | T10086-50
T10086-51 | C156 | CAP, TA, 47 µF, 16 V, +/- 20%, 0.6 ohm, SMD | 1 | Mouser | 647-F951C476MBAAQ2 | Kyocera AVX | F951C476MBAAQ2 |  | 51 | T10086-51 | 1 | 647-F951C476MBAAQ2 | T10086-51
T10086-52 | U17 | CC3220MODASF12MONR - IC RF TxRx + MCU WiFi 802.11b/g/n 2.4GHz 63-SMD Module, RoHS compliant | 1 | TI store | CC3220MODASF12MONR | Texas Instruments | CC3220MODASF12MONR |  | 52 | T10086-52 | 0 | CC3220MODASF12MONR | T10086-52
T10086-53 | R6_Ch1, R6_Ch2, R6_Ch3, R6_Ch4, R6_Ch5, R6_Ch6, R6_Ch7, R6_Ch8 | Current Sense Resistors - SMD 0.005ohms 0.1% 3w | 8 | Mouser | 71-CSM36370R0050FST | VPG Foil Resistors | Y14880R00500F9R |  | 53 | T10086-53 | 8 | 71-CSM36370R0050FST | T10086-53
T10086-54 | D2_Ch1, D2_Ch2, D2_Ch3, D2_Ch4, D2_Ch5, D2_Ch6, D2_Ch7, D2_Ch8 | Diode FERD (Field Effect Rectifier Diode) 100V 20A Surface Mount DPAK | 8 | Digi-Key | ‎497-16946-1-ND‎ | STMicroelectronics | FERD20H100SB-TR |  | 54 | T10086-54 | 8 | ‎497-16946-1-ND‎ | T10086-54
T10086-55 | D10 | Diode, Schottky, 100 V, 5 A, SMC | 1 | Digi-Key | 641-1124-1-ND | Comchip | CDBC5100-G |  | 55 | T10086-55 | 1 | 641-1124-1-ND | T10086-55
T10086-56 | D9 | Diode, Schottky, 30 V, 5 A, SMC | 1 | LCSC | C110488 | Diodes | B530C-13-F |  | 56 | T10086-56 | 1 | C110488 | T10086-56
T10086-57 | D1_Ch1, D1_Ch2, D1_Ch3, D1_Ch4, D1_Ch5, D1_Ch6, D1_Ch7, D1_Ch8, D3_Ch1, D3_Ch2, D3_Ch3, D3_Ch4, D3_Ch5, D3_Ch6, D3_Ch7, D3_Ch8, D4_Ch1, D4_Ch2, D4_Ch3, D4_Ch4, D4_Ch5, D4_Ch6, D4_Ch7, D4_Ch8, D7, D13, D34_Ch1, D34_Ch2, D34_Ch3, D34_Ch4, D34_Ch5, D34_Ch6, D34_Ch7, D34_Ch8, D35_Ch1, D35_Ch2, D35_Ch3, D35_Ch4, D35_Ch5, D35_Ch6, D35_Ch7, D35_Ch8 | Diode, Schottky, 40V, 0.25A, SOD-523 | 42 | Arrow Electronics | NSR0240V2T1G | ON Semiconductor | NSR0240V2T1G |  | 57 | T10086-57 | 42 | NSR0240V2T1G | T10086-57
T10086-58 | D8 | Diode, TVS, Uni, 18 V, 29.2 Vc, SMA | 1 | Digi-Key | SMAJ18ALFCT-ND | Littelfuse | SMAJ18A |  | 58 | T10086-58 | 1 | SMAJ18ALFCT-ND | T10086-58
T10086-59 | D5, D6 | Diode, Ultrafast, 100 V, 0.15 A, SOD-123 | 2 | Digi-Key | 1N4148W-FDICT-ND | Diodes | 1N4148W-7-F |  | 59 | T10086-59 | 2 | 1N4148W-FDICT-ND | T10086-59
T10086-60 | U8, U13 | Dual Schmitt-Trigger Buffer, DBV0006A, SMALL T&R | 2 | TI store | SN74LVC2G14DCKT | Texas Instruments | SN74LVC2G14DCKT |  | 60 | T10086-60 | 0 | SN74LVC2G14DCKT | T10086-60
T10086-61 | U4_Ch1, U4_Ch2, U4_Ch3, U4_Ch4, U4_Ch5, U4_Ch6, U4_Ch7, U4_Ch8 | Dual, Micropower, Push-Pull Outputs, LinCMOS(TM) Voltage Comparator | 8 | Digi-Key | 296-47277-1-ND | Texas Instruments | TLC3702CPWR |  | 61 | T10086-61 | 8 | 296-47277-1-ND | T10086-61
T10086-62 | L4 | Ferrite Bead, 1000 ohm @ 100 MHz, 1.5 A, 1806 | 1 | Digi-Key | 490-1061-1-ND | Murata | BLM41PG102SN1L |  | 62 | T10086-62 | 1 | 490-1061-1-ND | T10086-62
T10086-63 | F1_Ch1, F1_Ch2, F1_Ch3, F1_Ch4, F1_Ch5, F1_Ch6, F1_Ch7, F1_Ch8 | Fuse, 15 A, SMD | 8 | Element14 | 2135886 | Schurter | 3413.0330.22 |  | 63 | T10086-63 | 8 | 2135886 | T10086-63
T10086-64 | J2_Ch1, J2_Ch2, J2_Ch3, J2_Ch4, J2_Ch5, J2_Ch6, J2_Ch7, J2_Ch8, RT1_Ch1, RT1_Ch2, RT1_Ch3, RT1_Ch4, RT1_Ch5, RT1_Ch6, RT1_Ch7, RT1_Ch8 | Header (Shrouded), 2.5mm, 2x1, Tin, TH | 16 | Digi-Key | 455-1611-ND | JST | B2B-EH-A(LF)(SN) |  | 64 | T10086-64 | 16 | 455-1611-ND | T10086-64
T10086-65 | J4 | Header, 2.54mm, 3x1, Tin, TH | 1 | Digi-Key | WM50016-03-ND | Molex | 0022284033 |  | 65 | T10086-65 | 0 | WM50016-03-ND | T10086-65
T10086-66 | I2C | Header, 3-Pin | 1 |  |  |  |  |  | 66 | T10086-66 | 0 | 0 | T10086-66
T10086-67 | LED | Header, 4-Pin | 1 |  |  |  |  |  | 67 | T10086-67 | 0 | 0 | T10086-67
T10086-68 | CAN | Header, 5-Pin | 1 |  |  |  |  |  | 68 | T10086-68 | 0 | 0 | T10086-68
T10086-69 | U1_Ch1, U1_Ch2, U1_Ch3, U1_Ch4, U1_Ch5, U1_Ch6, U1_Ch7, U1_Ch8 | High Voltage 1A Peak Half Bridge Gate Driver, 8-pin Narrow SOIC, Pb-Free | 8 | TI store | LM5109BMAX/NOPB | TI National Semiconductor | LM5109BMAX/NOPB |  | 69 | T10086-69 | 0 | LM5109BMAX/NOPB | T10086-69
T10086-70 | U11 | High-Side Protection Controller with Low Quiescent Current, 10-pin MSOP, Pb-Free | 1 | Digi-Key | 296-39024-1-ND | TI National Semiconductor | LM5060MM/NOPB |  | 70 | T10086-70 | 1 | 296-39024-1-ND | T10086-70
T10086-71 | U34 | IC FRAM 1M I2C 3.4MHZ 8SOIC | 1 | Digi-Key | 428-3197-ND | Cypress | FM24V10-G |  | 71 | T10086-71 | 0 | 428-3197-ND | T10086-71
T10086-72 | L3 | Inductor, Shielded Drum Core, Ferrite, 47 µH, 2.9 A, 0.07 ohm, SMD | 1 | Element14 | 2288508 | Coilcraft | MSS1278-473MLD |  | 72 | T10086-72 | 1 | 2288508 | T10086-72
T10086-73 | L1_Ch1, L1_Ch2, L1_Ch3, L1_Ch4, L1_Ch5, L1_Ch6, L1_Ch7, L1_Ch8 | Inductor, Shielded Drum Core, Powdered Iron, 1 uH, 5 A, 0.022 ohm, SMD | 8 | Digi-Key | 732-3342-1-ND | Wurth Electronics | 74437324010 |  | 73 | T10086-73 | 0 | 732-3342-1-ND | T10086-73
T10086-74 | L6 | Inductor, Shielded, Composite, 4.7 µH, 2.7 A, 0.05 ohm, SMD | 1 | Element14 | 2289218 | Coilcraft | XFL4020-472MEC |  | 74 | T10086-74 | 1 | 2289218 | T10086-74
T10086-75 | L2_Ch1, L2_Ch2, L2_Ch3, L2_Ch4, L2_Ch5, L2_Ch6, L2_Ch7, L2_Ch8 | Inductor, Shielded, Mn-Zn, 47 µH, 13 A, 0.00968 ohm, SMD | 8 | Digi-Key | 732-11713-ND | Wurth Electronics | 74437529203470 |  | 75 | T10086-75 | 0 | 732-11713-ND | T10086-75
T10086-76 | L5 | Inductor, Wirewound, 4.7 uH, 0.95 A, 0.38 ohm, SMD | 1 | Digi-Key | 587-5927-1-ND | Taiyo Yuden | MAKK2016T4R7M |  | 76 | T10086-76 | 1 | 587-5927-1-ND | T10086-76
T10086-77 | D11, D14, D15, D17, D18, D33, D36_Ch1, D36_Ch2, D36_Ch3, D36_Ch4, D36_Ch5, D36_Ch6, D36_Ch7, D36_Ch8 | LED, Green, SMD | 14 | Digi-Key | 732-4980-1-ND | Wurth Electronics | 150060VS75000 |  | 77 | T10086-77 | 14 | 732-4980-1-ND | T10086-77
T10086-78 | U33, U41 | LOW POWER HIGH SPEED OP AMP | 2 | TI store | OPA837IDBVR | Texas Instruments | OPA837IDBVR |  | 78 | T10086-78 | 0 | OPA837IDBVR | T10086-78
T10086-79 | U32, U414 | Low-Noise, 900 kHz, RRIO, Precision Operational Amplifier, Zerø-Drift Series, 2.2 to 5.5 V, -40 to 125 degC, 5-pin SOT23 (DBV0005A), Green (RoHS & no Sb/Br) | 2 | TI store | OPA378AIDBVT | Texas Instruments | OPA378AIDBVT |  | 79 | T10086-79 | 0 | OPA378AIDBVT | T10086-79
T10086-80 | Q5, Q6 | MOSFET, N-CH, 100 V, 21 A, PowerPAK SO-8 | 2 | Digi-Key | ‎SI7454DDP-T1-GE3CT-ND‎ | Vishay Siliconix | SI7454DDP-T1-GE3 |  | 80 | T10086-80 | 2 | ‎SI7454DDP-T1-GE3CT-ND‎ | T10086-80
T10086-81 | Q2, Q3, Q8_Ch1, Q8_Ch2, Q8_Ch3, Q8_Ch4, Q8_Ch5, Q8_Ch6, Q8_Ch7, Q8_Ch8 | MOSFET, N-CH, 25 V, 100 A, DNK0008A (VSON-CLIP-8) | 10 | Digi-Key | CSD16570Q5B-ND | Texas Instruments | CSD16570Q5B |  | 81 | T10086-81 | 0 | CSD16570Q5B-ND | T10086-81
T10086-82 | Q1_Ch1, Q1_Ch2, Q1_Ch3, Q1_Ch4, Q1_Ch5, Q1_Ch6, Q1_Ch7, Q1_Ch8, Q7_Ch1, Q7_Ch2, Q7_Ch3, Q7_Ch4, Q7_Ch5, Q7_Ch6, Q7_Ch7, Q7_Ch8 | MOSFET, N-CH, 40 V, 15 A, DQJ0008A (VSONP-8) | 16 | TI store | CSD18504Q5A | Texas Instruments | CSD18504Q5A |  | 82 | T10086-82 | 0 | CSD18504Q5A | T10086-82
T10086-83 | U40_Ch1, U40_Ch2, U40_Ch3, U40_Ch4, U40_Ch5, U40_Ch6, U40_Ch7, U40_Ch8 | No Description Available | 8 | TI store | TLV9001IDCKR | Texas Instruments | TLV9001IDCKR |  | 83 | T10086-83 | 0 | TLV9001IDCKR | T10086-83
T10086-84 | U3_Ch1, U3_Ch2, U3_Ch3, U3_Ch4, U3_Ch5, U3_Ch6, U3_Ch7, U3_Ch8, U36_Ch1, U36_Ch2, U36_Ch3, U36_Ch4, U36_Ch5, U36_Ch6, U36_Ch7, U36_Ch8 | Noise Low-Power Precision Instrumentation Amplifier 35uV Offset 8nV/√Hz 8-Pin SOIC T/R | 16 | TI store | INA818IDR | Texas Instruments | INA818IDR |  | 84 | T10086-84 | 0 | INA818IDR | T10086-84
T10086-85 | U37_Ch1, U37_Ch2, U37_Ch3, U37_Ch4, U37_Ch5, U37_Ch6, U37_Ch7, U37_Ch8 | Precision, 20 MHz, 0.9 pA Ib, RRIO, CMOS Operational Amplifier, 1.8 to 5.5 V, -40 to 125 degC, 5-pin SOT23 (DBV5), Green (RoHS & no Sb/Br) | 8 | TI store | OPA320AIDBVR | Texas Instruments | OPA320AIDBVR |  | 85 | T10086-85 | 0 | OPA320AIDBVR | T10086-85
T10086-86 | U26, U27 | Priority Encoder 1 x 8:3 16-SOIC | 2 | TI store | SN74HC148DR | Texas Instruments | SN74HC148DR |  | 86 | T10086-86 | 0 | SN74HC148DR | T10086-86
T10086-87 | R221_Ch1, R221_Ch2, R221_Ch3, R221_Ch4, R221_Ch5, R221_Ch6, R221_Ch7, R221_Ch8 | RES SMD 3k OHM 0.1% 1/10W 0603 | 8 | Digi-Key | P3.0KYDKR-ND | Panasonic | ERA-3YEB302V |  | 87 | T10086-87 | 8 | P3.0KYDKR-ND | T10086-87
T10086-88 | R152, R153 | RES, 0, 1%, 0.5 W, 1206 | 2 | Digi-Key | 36-5108CT-ND | Keystone Electronics | 5108 |  | 88 | T10086-88 | 0 | 36-5108CT-ND | T10086-88
T10086-89 | R7_Ch1, R7_Ch2, R7_Ch3, R7_Ch4, R7_Ch5, R7_Ch6, R7_Ch7, R7_Ch8, R10_Ch1, R10_Ch2, R10_Ch3, R10_Ch4, R10_Ch5, R10_Ch6, R10_Ch7, R10_Ch8, R12_Ch1, R12_Ch2, R12_Ch3, R12_Ch4, R12_Ch5, R12_Ch6, R12_Ch7, R12_Ch8, R13_Ch1, R13_Ch2, R13_Ch3, R13_Ch4, R13_Ch5, R13_Ch6, R13_Ch7, R13_Ch8, R14_Ch1, R14_Ch2, R14_Ch3, R14_Ch4, R14_Ch5, R14_Ch6, R14_Ch7, R14_Ch8, R17_Ch1, R17_Ch2, R17_Ch3, R17_Ch4, R17_Ch5, R17_Ch6, R17_Ch7, R17_Ch8, R20_Ch1, R20_Ch2, R20_Ch3, R20_Ch4, R20_Ch5, R20_Ch6, R20_Ch7, R20_Ch8, R31_Ch1, R31_Ch2, R31_Ch3, R31_Ch4, R31_Ch5, R31_Ch6, R31_Ch7, R31_Ch8, R34_Ch1, R34_Ch2, R34_Ch3, R34_Ch4, R34_Ch5, R34_Ch6, R34_Ch7, R34_Ch8, R36_Ch1, R36_Ch2, R36_Ch3, R36_Ch4, R36_Ch5, R36_Ch6, R36_Ch7, R36_Ch8, R39_Ch1, R39_Ch2, R39_Ch3, R39_Ch4, R39_Ch5, R39_Ch6, R39_Ch7, R39_Ch8, R40_Ch1, R40_Ch2, R40_Ch3, R40_Ch4, R40_Ch5, R40_Ch6, R40_Ch7, R40_Ch8, R43, R47, R49, R51-R55, R57, R60, R68_Ch1, R68_Ch2, R68_Ch3, R68_Ch4, R68_Ch5, R68_Ch6, R68_Ch7, R68_Ch8, R73_Ch1, R73_Ch2, R73_Ch3, R73_Ch4, R73_Ch5, R73_Ch6, R73_Ch7, R73_Ch8, R74_Ch1, R74_Ch2, R74_Ch3, R74_Ch4, R74_Ch5, R74_Ch6, R74_Ch7, R74_Ch8, R79, R86, R90-R96, R99-R107, R110-R127, R130-R138, R141-R151, R159, R160, R162, R164-R166, R168-R175, R178, R184, R185_Ch1, R185_Ch2, R185_Ch3, R185_Ch4, R185_Ch5, R185_Ch6, R185_Ch7, R185_Ch8, R186, R187, R192, R193, R204, R220, R222, R245, R247, R249-R257, R261-R276, R278, R281, R283, R289, R290_Ch1, R290_Ch2, R290_Ch3, R290_Ch4, R290_Ch5, R290_Ch6, R290_Ch7, R290_Ch8, R293-R297, R300, R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 | RES, 0, 5%, 0.063 W, 0402 | 266 | Digi-Key | 541-0.0JCT-ND | Vishay | CRCW04020000Z0ED |  | 89 | T10086-89 | 266 | 541-0.0JCT-ND | T10086-89
T10086-90 | R2_Ch1, R2_Ch2, R2_Ch3, R2_Ch4, R2_Ch5, R2_Ch6, R2_Ch7, R2_Ch8, R3_Ch1, R3_Ch2, R3_Ch3, R3_Ch4, R3_Ch5, R3_Ch6, R3_Ch7, R3_Ch8, R8_Ch1, R8_Ch2, R8_Ch3, R8_Ch4, R8_Ch5, R8_Ch6, R8_Ch7, R8_Ch8 | RES, 0, 5%, 0.1 W, 0603 | 24 | Digi-Key | 311-0.0GRCT-ND | Yageo | RC0603JR-070RL |  | 90 | T10086-90 | 24 | 311-0.0GRCT-ND | T10086-90
T10086-91 | R163, R176, R201, R205 | RES, 0, 5%, 0.1 W, 0603 | 4 | Digi-Key | P0.0GCT-ND | Panasonic | ERJ-3GEY0R00V |  | 91 | T10086-91 | 4 | P0.0GCT-ND | T10086-91
T10086-92 | R211 | RES, 0.068, 1%, 1 W, 0612 | 1 | Mouser | 754-PRL1632-R068-FT1 | Susumu | PRL1632-R068-F-T1 |  | 92 | T10086-92 | 1 | 754-PRL1632-R068-FT1 | T10086-92
T10086-93 | R7, R157 | RES, 0.22, 1%, 0.1 W, 0603 | 2 | Digi-Key | P.22AJCT-ND | Panasonic | ERJ-3RQFR22V |  | 93 | T10086-93 | 2 | P.22AJCT-ND | T10086-93
T10086-94 | R28_Ch1, R28_Ch2, R28_Ch3, R28_Ch4, R28_Ch5, R28_Ch6, R28_Ch7, R28_Ch8, R29_Ch1, R29_Ch2, R29_Ch3, R29_Ch4, R29_Ch5, R29_Ch6, R29_Ch7, R29_Ch8, R155, R218, R485, R491 | RES, 1.00 k, 0.1%, 0.1 W, 0603 | 20 | Digi-Key | RG16P1.0KBCT-ND | Susumu | RG1608P-102-B-T5 |  | 94 | T10086-94 | 20 | RG16P1.0KBCT-ND | T10086-94
T10086-95 | R15_Ch1, R15_Ch2, R15_Ch3, R15_Ch4, R15_Ch5, R15_Ch6, R15_Ch7, R15_Ch8, R87 | RES, 1.00 M, 1%, 0.1 W, 0603 | 9 | Digi-Key | 541-1.00MHCT-ND | Vishay | CRCW06031M00FKEA |  | 95 | T10086-95 | 0 | 541-1.00MHCT-ND | T10086-95
T10086-96 | R19_Ch1, R19_Ch2, R19_Ch3, R19_Ch4, R19_Ch5, R19_Ch6, R19_Ch7, R19_Ch8, R25_Ch1, R25_Ch2, R25_Ch3, R25_Ch4, R25_Ch5, R25_Ch6, R25_Ch7, R25_Ch8, R75_Ch1, R75_Ch2, R75_Ch3, R75_Ch4, R75_Ch5, R75_Ch6, R75_Ch7, R75_Ch8 | RES, 1.00, 1%, 0.1 W, 0603 | 24 | Digi-Key | 311-1.00HRCT-ND | Yageo | RC0603FR-071RL |  | 96 | T10086-96 | 24 | 311-1.00HRCT-ND | T10086-96
T10086-97 | R223-R238, R240-R242, R244, R258, R259 | RES, 10.0 k, 1%, 0.063 W, 0402 | 22 | Digi-Key | 541-10.0KLCT-ND | Vishay | CRCW0402-10K0FKED |  | 97 | T10086-97 | 22 | 541-10.0KLCT-ND | T10086-97
T10086-98 | R1_Ch1, R1_Ch2, R1_Ch3, R1_Ch4, R1_Ch5, R1_Ch6, R1_Ch7, R1_Ch8, R5_Ch1, R5_Ch2, R5_Ch3, R5_Ch4, R5_Ch5, R5_Ch6, R5_Ch7, R5_Ch8, R18_Ch1, R18_Ch2, R18_Ch3, R18_Ch4, R18_Ch5, R18_Ch6, R18_Ch7, R18_Ch8, R24_Ch1, R24_Ch2, R24_Ch3, R24_Ch4, R24_Ch5, R24_Ch6, R24_Ch7, R24_Ch8, R44_Ch1, R44_Ch2, R44_Ch3, R44_Ch4, R44_Ch5, R44_Ch6, R44_Ch7, R44_Ch8, R45_Ch1, R45_Ch2, R45_Ch3, R45_Ch4, R45_Ch5, R45_Ch6, R45_Ch7, R45_Ch8, R46_Ch1, R46_Ch2, R46_Ch3, R46_Ch4, R46_Ch5, R46_Ch6, R46_Ch7, R46_Ch8, R82, R88, R89, R161_Ch1, R161_Ch2, R161_Ch3, R161_Ch4, R161_Ch5, R161_Ch6, R161_Ch7, R161_Ch8, R190, R191, R194, R195 | RES, 10.0 k, 1%, 0.1 W, 0603 | 71 | Digi-Key | 311-10.0KHRCT-ND | Mepco Philips | RC0603FR-0710KL |  | 98 | T10086-98 | 100 | 311-10.0KHRCT-ND | T10086-98
T10086-99 | R215 | RES, 10.0, 1%, 0.1 W, 0603 | 1 | Digi-Key | 541-10.0HCT-ND | Vishay | CRCW060310R0FKEA |  | 99 | T10086-99 | 0 | 541-10.0HCT-ND | T10086-99
T10086-100 | R9_Ch1, R9_Ch2, R9_Ch3, R9_Ch4, R9_Ch5, R9_Ch6, R9_Ch7, R9_Ch8 | RES, 10.0, 1%, 0.25 W, 1206 | 8 | Digi-Key | 311-10.0FRCT-ND | Yageo | RC1206FR-0710RL |  | 100 | T10086-100 | 8 | 311-10.0FRCT-ND | T10086-100
T10086-101 | R64_Ch1, R64_Ch2, R64_Ch3, R64_Ch4, R64_Ch5, R64_Ch6, R64_Ch7, R64_Ch8, R70_Ch1, R70_Ch2, R70_Ch3, R70_Ch4, R70_Ch5, R70_Ch6, R70_Ch7, R70_Ch8 | RES, 100 k, 0.1%, 0.1 W, 0603 | 16 | LCSC | C190609 | Panasonic | ERA-3AEB104V |  | 101 | T10086-101 | 0 | C190609 | T10086-101
T10086-102 | R198, R200 | RES, 100 k, 0.5%, 0.063 W, 0402 | 2 | Digi-Key | 541-100KAVCT-ND | Vishay Dale | CRCW0402100KDHEDP |  | 102 | T10086-102 | 2 | 541-100KAVCT-ND | T10086-102
T10086-103 | R42, R108, R109, R139, R140, R167, R177, R181, R207, R306, R317, R318 | RES, 100 k, 1%, 0.1 W, 0603 | 12 | Digi-Key | 311-100KHRCT-ND | Mepco Philips | RC0603FR-07100KL |  | 103 | T10086-103 | 0 | 311-100KHRCT-ND | T10086-103
T10086-104 | R202 | RES, 100 k, 1%, 0.1 W, 0603 | 1 | Digi-Key | 541-100KHCT-ND | Vishay | CRCW0603100KFKEA |  | 104 | T10086-104 | 0 | 541-100KHCT-ND | T10086-104
T10086-105 | R37_Ch1, R37_Ch2, R37_Ch3, R37_Ch4, R37_Ch5, R37_Ch6, R37_Ch7, R37_Ch8, R66_Ch1, R66_Ch2, R66_Ch3, R66_Ch4, R66_Ch5, R66_Ch6, R66_Ch7, R66_Ch8, R287_Ch1, R287_Ch2, R287_Ch3, R287_Ch4, R287_Ch5, R287_Ch6, R287_Ch7, R287_Ch8 | RES, 11.0 k, 1%, 0.063 W, 0402 | 24 | Digi-Key | 541-11.0KLCT-ND | Vishay | CRCW040211K0FKED |  | 105 | T10086-105 | 24 | 541-11.0KLCT-ND | T10086-105
T10086-106 | R260, R303 | RES, 13 k, 0.1%, 0.1 W, 0603 | 2 | Digi-Key | RNCP0603FTD13K0CT-ND | Stackpole Electronics Inc | RNCP0603FTD13K0 |  | 106 | T10086-106 | 2 | RNCP0603FTD13K0CT-ND | T10086-106
T10086-107 | R197 | RES, 130 k, 1%, 0.063 W, 0402 | 1 | Digi-Key | 541-130KLCT-ND | Vishay | CRCW0402130KFKED |  | 107 | T10086-107 | 1 | 541-130KLCT-ND | T10086-107
T10086-108 | R210 | RES, 18.2 k, 1%, 0.1 W, 0603 | 1 | Digi-Key | 541-18.2KHCT-ND | Vishay | CRCW060318K2FKEA |  | 108 | T10086-108 | 1 | 541-18.2KHCT-ND | T10086-108
T10086-109 | R78, R489 | RES, 2.0, 5%, 0.1 W, 0603 | 2 | Digi-Key | 541-2.0GCT-ND | Vishay Dale | CRCW06032R00JNEA |  | 109 | T10086-109 | 2 | 541-2.0GCT-ND | T10086-109
T10086-110 | R80 | RES, 2.00 k, 1%, 0.1 W, 0603 | 1 | Digi-Key | 541-2.00KHCT-ND | Vishay | CRCW06032K00FKEA |  | 110 | T10086-110 | 1 | 541-2.00KHCT-ND | T10086-110
T10086-111 | R11_Ch1, R11_Ch2, R11_Ch3, R11_Ch4, R11_Ch5, R11_Ch6, R11_Ch7, R11_Ch8, R21_Ch1, R21_Ch2, R21_Ch3, R21_Ch4, R21_Ch5, R21_Ch6, R21_Ch7, R21_Ch8, R62_Ch1, R62_Ch2, R62_Ch3, R62_Ch4, R62_Ch5, R62_Ch6, R62_Ch7, R62_Ch8 | RES, 2.00, 1%, 0.1 W, 0603 | 24 | Digi-Key | 541-2.00HHCT-ND | Vishay Dale | CRCW06032R00FKEA |  | 111 | T10086-111 | 24 | 541-2.00HHCT-ND | T10086-111
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

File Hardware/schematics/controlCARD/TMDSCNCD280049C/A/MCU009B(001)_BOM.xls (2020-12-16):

Filename: | #VALUE!
Variant: | 001
Generated: | 3/20/18 4:23:23 PM
 |  | TMDSCNCD280049C
Designator | Quantity | Value | Description | PackageReference | PartNumber | Manufacturer | Alternate PartNumber | Alternate Manufacturer
!PCB1 | 1 |  | Printed Circuit Board |  | MCU009 | Any
C1, C2, C8, C24, C27 | 5 | 10uF | CAP, CERM, 10 uF, 10 V, +/- 20%, X5R, 0603 | 0603 | GRM188R61A106ME69D | MuRata
C1:A, C3, C4, C5, C6, C6:A, C7:A, C8:A, C9, C9:A, C10:A, C11:A, C12:A, C14, C14:A, C15, C16, C16:A, C17, C18, C19:A, C20:A, C21:A, C22:A, C23:A, C24:A, C25, C25:A, C31, C32, C33 | 31 | 0.1uF | CAP, CERM, 0.1 uF, 10 V, +/- 10%, X7R, 0402 | 0402 | GRM155R71A104KA01D | MuRata
C2:A, C3:A, C5:A, C13:A, C15:A | 5 | 4.7uF | CAP, CERM, 4.7 uF, 6.3 V, +/- 20%, X5R, 0603 | 0603 | GRM188R60J475ME19D | MuRata
C4:A, C26, C29, C30 | 4 | 0.01uF | CAP, CERM, 0.01 uF, 16 V, +/- 10%, X7R, 0402 | 0402 | GRM155R71C103KA01D | MuRata
C7 | 1 | 10uF | CAP, CERM, 10 uF, 10 V, +/- 10%, X5R, 0805 | 0805 | GRM21BR61A106KE19L | MuRata
C10, C11, C12, C13, C60, C61 | 6 | 2.2uF | CAP, CERM, 2.2 uF, 10 V, +/- 10%, X5R, 0603 | 0603 | GRM188R61A225KE34D | MuRata
C17:A, C18:A | 2 | 27pF | CAP, CERM, 27 pF, 50 V, +/- 5%, C0G/NP0, 0402 | 0402 | GRM1555C1H270JA01D | MuRata
C22, C23 | 2 | 15pF | CAP, CERM, 15 pF, 50 V, +/- 5%, C0G/NP0, 0402 | 0402 | GRM1555C1H150JA01D | MuRata
C26:A | 1 | 0.01uF | CAP, CERM, 0.01 uF, 1500 V, +/- 10%, X7R, 1812 | 1812 | 1812SC103KAT1A | AVX
C34, C35, C36, C37, C38, C39, C40 | 7 | 330pF | CAP, CERM, 330 pF, 50 V, +/- 5%, C0G/NP0, 0603 | 0603 | GRM1885C1H331JA01D | MuRata
D1, D2:A | 2 | Bright Green | LED, Bright Green, SMD | LED_0805 | 150080VS75000 | Wurth Elektronik
D1:A | 1 | 10V | Diode, Schottky, 10 V, 1 A, AEC-Q101, POWERMITE | POWERMITE | MBRM110ET1G | ON Semiconductor
D2, D3 | 2 | Red | LED, Red, SMD | LED_0805 | 150080SS75000 | Wurth Elektronik
D3:A, D4:A | 2 | Blue | LED, Blue, SMD | LED_0805 | 150080BS75000 | Wurth Elektronik
J1 | 1 |  | Header, 2mm, 4x2, Tin, TH | Header, 2mm, 4x2, TH | TMM-104-01-T-D | Samtec
J1:A | 1 |  | Connector, Receptacle, USB Mini B 2.0, SMT | Connector, Receptacle, USB Mini B 2.0, 5 Position, SMT | 65100516121 | Wurth Elektronik
L1 | 1 | 220 ohm | Ferrite Bead, 220 ohm @ 100 MHz, 2 A, 0805 | 0805 | BLM21PG221SN1D | MuRata
L1:A, L2:A | 2 | 600 ohm | Ferrite Bead, 600 ohm @ 100 MHz, 0.5 A, 0805 | 0805 | HZ0805E601R-10 | Laird-Signal Integrity Products
L2 | 1 | 60 ohm | Ferrite Bead, 60 ohm @ 100 MHz, 3 A, 0805 | 0805 | BKP2125HS600-T | Taiyo Yuden
L3 | 1 | 2.2uH | Inductor, Multilayer, Ferrite, 2.2 uH, 1.3 A, 0.08 ohm, SMD | SMD, Body 2.5x2mm, Height 1.2mm | LQM2HPN2R2MG0L | MuRata
R1, R2 | 2 | 4.7k | RES, 4.7 k, 5%, 0.063 W, AEC-Q200 Grade 0, 0402 | 0402 | CRCW04024K70JNED | Vishay-Dale
R1:A, R10, R11, R23 | 4 | 680 | RES, 680, 5%, 0.063 W, AEC-Q200 Grade 0, 0402 | 0402 | CRCW0402680RJNED | Vishay-Dale
R2:A, R4:A, R8, R9, R9:A, R15:A, R16:A | 7 | 10k | RES, 10 k, 5%, 0.063 W, AEC-Q200 Grade 0, 0402 | 0402 | CRCW040210K0JNED | Vishay-Dale
R3, R4, R5, R6, R16, R18, R19, R32, R35, R36, R37, R38, R39, R40, R41, R42, R43, R44, R45, R46, R47, R48, R49, R50, R51, R52, R53, R54, R60, R61, R62, R63, R64 | 33 | 0 | RES, 0, 5%, 0.1 W, AEC-Q200 Grade 0, 0603 | 0603 | CRCW06030000Z0EA | Vishay-Dale
R3:A, R6:A, R29 | 3 | 0 | RES, 0, 5%, 0.063 W, AEC-Q200 Grade 0, 0402 | 0402 | CRCW04020000Z0ED | Vishay-Dale
R5:A, R7:A, R8:A, R11:A | 4 | 1.0k | RES, 1.0 k, 5%, 0.063 W, AEC-Q200 Grade 0, 0402 | 0402 | CRCW04021K00JNED | Vishay-Dale
R10:A, R27, R30, R31, R33, R34 | 6 | 2.2k | RES, 2.2 k, 5%, 0.063 W, AEC-Q200 Grade 0, 0402 | 0402 | CRCW04022K20JNED | Vishay-Dale
R12, R13 | 2 | 10Meg | RES, 10 M, 5%, 0.063 W, AEC-Q200 Grade 0, 0402 | 0402 | CRCW040210M0JNED | Vishay-Dale
R14, R15, R20 | 3 | 0 | RES, 0, 5%, 0.125 W, AEC-Q200 Grade 0, 0805 | 0805 | CRCW08050000Z0EA | Vishay-Dale
R14:A | 1 | 12k | RES, 12 k, 5%, 0.063 W, AEC-Q200 Grade 0, 0402 | 0402 | CRCW040212K0JNED | Vishay-Dale
R25, R26 | 2 | 56k | RES, 56 k, 5%, 0.063 W, AEC-Q200 Grade 0, 0402 | 0402 | CRCW040256K0JNED | Vishay-Dale
S1, S1:A, S8 | 3 |  | Switch, SPST, 2 Pos, 25mA, 24VDC, SMD | 3.71x5.8mm | 218-2LPST | CTS Electrocomponents
S2, S3, S4 | 3 |  | SLIDE SWITCH DPDT .1A, SMT | SWITCH, 5.4x2.5x3.9mm | CAS-220TA | Copal Electronics
S5, S6 | 2 |  | Switch, Dual SPDT, 2 Pos, 0.1A, 6VDC, SMD | 5.4x3.9mm | CAS-D20TA | Copal Electronics
S7 | 1 |  | Switch, SPST, 8 Pos, 25mA, 24VDC, SMD | 11.33x5.8mm | 218-8LPST | CTS Electrocomponents
U1 | 1 |  | Piccolo Microcontroller, PZ0100A (LQFP-100) | PZ0100A | F280049CPZS | Texas Instruments |  | Texas Instruments
U1:A | 1 |  | Low-Noise, High PSRR, RF 200-mA Low-Dropout Linear Regulators, DBV0005A (SOT-23-5) | DBV0005A | TPS73033DBVR | Texas Instruments | TPS73033DBVT | Texas Instruments
U2 | 1 |  | Dual Buffer/Driver with Open-Drain Output, DBV0006A, LARGE T&R | DBV0006A | SN74LVC2G07DBVR | Texas Instruments
U2:A | 1 |  | Dual High Speed USB To Multipurpose UART/FIFO IC, LQFP-64 | LQFP_10x10mm | FT2232HL-REEL | FTDI
U3 | 1 |  | Single Output Low Noise LDO, 400 mA, Fixed 3.3 V Output, 1.7 to 5.5 V Input, with Reverse Current Protection, 5-pin SOT-23 (DBV), -40 to 85 degC, Green (RoHS & no Sb/Br) | DBV0005A | TPS73633DBVR | Texas Instruments | TPS73633DBVT | Texas Instruments
U3:A | 1 |  | Low-Capacitance + / - 15 kV ESD-Protection Array for High-Speed Data Interfaces, 2 Channels, -40 to +85 degC, 5-pin SOT (DRL), Green (RoHS & no Sb/Br) | DRL0005A | TPD2E001DRLR | Texas Instruments
U4 | 1 |  | High-Accuracy, Fixed-Threshold OV/UV Monitor, DDC0006A (SOT-23-T-6) | DDC0006A | TPS3702CX33DDCR | Texas Instruments | TPS3702CX33DDCT | Texas Instruments
U4:A | 1 |  | 2K Microwire Compatible Serial EEPROM, SOIC-8 | SOIC-8 | 93LC56C-I/SN | Microchip
U5, U6, U7, U8, U9 | 5 |  | Automotive Low-Capacitance 4-Channel +/-15-kV ESD Protection Array for High-Speed Data Interfaces, DBV0006A (SOT-23-6) | DBV0006A | TPD4E001QDBVRQ1 | Texas Instruments |  | Texas Instruments
U5:A, U6:A, U7:A | 3 |  | 25 Mbps Dual Channels, 2 / 0, Digital Isolator, 3.3 V / 5 V, -40 to +125 degC, 8-pin SOIC (D), Green (RoHS & no Sb/Br) | D0008B | ISO7220CD | Texas Instruments
U8:A | 1 |  | Octal Buffer/Driver With 3-State OUtputs, PW0020A (TSSOP-20) | PW0020A | SN74ALVC244PWR | Texas Instruments | SN74ALVC244PW | Texas Instruments
Y1 | 1 |  | Crystal, 20 MHz, 25 ppm, 18, SMD | 5x3.2mm | ECS-200-18-30B-AGN-TR | ECS Inc.
Y1:A | 1 |  | Crystal, 12 MHz, 20pF, SMD | 5x3.2mm | ECS-120-20-30B-TR | ECS Inc.
C19 | 0 | 2.2uF | CAP, CERM, 2.2 uF, 10 V, +/- 10%, X5R, 0603 | 0603 | GRM188R61A225KE34D | MuRata
C20, C21 | 0 | 10uF | CAP, CERM, 10 uF, 10 V, +/- 20%, X5R, 0603 | 0603 | GRM188R61A106ME69D | MuRata
C28 | 0 | 1000pF | CAP, CERM, 1000 pF, 16 V, +/- 10%, X7R, 0402 | 0402 | GRM155R71C102KA01D | MuRata
C41, C42, C43, C44, C45, C46, C47, C48, C49, C50, C51, C52, C53, C54, C55, C56, C57, C58, C59 | 0 | 0.1uF | CAP, CERM, 0.1 uF, 16 V, +/- 10%, X7R, 0603 | 0603 | GRM188R71C104KA01D | MuRata
FID1, FID2, FID3, FID4, FID5, FID6 | 0 |  | Fiducial mark. There is nothing to buy or mount. | N/A | N/A | N/A
R7, R17, R21, R22, R28, R55, R56, R57, R58, R59 | 0 | 0 | RES, 0, 5%, 0.1 W, AEC-Q200 Grade 0, 0603 | 0603 | CRCW06030000Z0EA | Vishay-Dale
R12:A, R13:A | 0 | 0 | RES, 0, 5%, 0.063 W, AEC-Q200 Grade 0, 0402 | 0402 | CRCW04020000Z0ED | Vishay-Dale
R24 | 0 | 1.00 | RES, 1.00, 1%, 0.063 W, AEC-Q200 Grade 0, 0402 | 0402 | CRCW04021R00FKED | Vishay-Dale
 |  | Notes:
 |  | Unless otherwise noted in the Alternate PartNumber and/or Alternate Manufacturer columns, all parts may be substituted with equivalents.

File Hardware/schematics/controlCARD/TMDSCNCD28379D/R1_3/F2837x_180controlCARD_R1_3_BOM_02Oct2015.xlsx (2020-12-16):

F2837x controlCARD Bill of Materials
R1.3 | V1 - 01Oct2015
ITEM | REF-DES | QTY | VALUE | PART NUMBER | DIGIKEY PART NUMBER | DESCRIPTION
1 | A:C1 A:C6-12 A:C14 A:C16 A:C20-28 C1-2 C4 C6 C9-13 C42 C44 C49-65 C67 C76-81 C84-90 | 61 | 100n |  |  | CAP CER 16V 10% X7R 0402
2 | A:C4 C3 C5 | 3 | 10n |  |  | CAP CER 16V 10% X7R 0402
3 | C45-47 | 3 | 1u |  |  | CAP CER 6.3V 10% X7R 0402
4 | C68 | 1 | DNP |  |  | CAP CER 16V 10% X7R 0402
5 | C7-8 | 2 | 15p |  |  | CAP CER 50V NP0 0402
6 | A:C18-19 | 2 | 27p |  |  | CAP CER 50V NP0 0402
7 | C69 | 1 | 33p |  |  | CAP CER 50V NP0 0402
8 | A:C2 C72-73 C75 | 4 | 10u |  |  | CAP CER 6.3V 20% X5R 0603
9 | C43 C83 C92 | 3 | 2u2 |  |  | CAP CER 10V 20% X5R 0603
10 | A:C5 A:C13 A:C15 C95 | 4 | 4u7 |  |  | CAP CER 6.3V 10% X5R 0603
11 | C18-41 | 24 | DNP |  |  | CAP CER 16V 10% X7R 0603
12 | C71 C74 | 2 | 10u |  |  | CAP CER 10V 20% X5R 0805
13 | C14-17 | 4 | 22u |  |  | CAP CER 10V 20% X5R/X7S 0805
14 | C48 C66 C70 | 3 | 22u |  |  | CAP CER 6.3V 20% X5R 0805
15 | C82 C91 | 2 | 2u2 |  |  | CAP CER 10V 20% X5R 0805
16 | C93 | 1 | DNP |  |  | CAP TANT 20% 1206
17 | J1 | 1 | HEADER_HSEC8-180_EDGE |  |  | 180 pin (120 + 60) HSEC8 fingers; mates with samtec connectors
18 | A:D3-4 | 2 | BLUE |  |  | LED BLUE 0805 SMD, Clear, 470nm
19 | A:D2 LD1 | 2 | GREEN |  |  | LED GREEN 0805 SMD, Diffused, 567nm
20 | LD2-3 | 2 | RED |  |  | LED RED 0805 SMD, Diffused, 647nm
21 | R73 | 1 | 200K |  |  | RES 1/16W 0.5% 0402 SMD
22 | R72 | 1 | 205K |  |  | RES 1/16W 1% 0402 SMD
23 | R65 | 1 | 22K |  |  | RES 1/16W 1% 0402 SMD
24 | R68 | 1 | 2K |  |  | RES 1/16W 1% 0402 SMD
25 | R66 | 1 | 340K |  |  | RES 1/16W 1% 0402 SMD
26 | R1-2 | 2 | 4K7 |  |  | RES 1/16W 1% 0402 SMD
27 | R70 | 1 | 75K |  |  | RES 1/16W 0.5% 0402 SMD
28 | A:R7 A:R10 R12 R25-26 R55-58 R63-64 R76-77 | 13 | 0 |  |  | RES 1/16W 5% 0402 SMD
29 | A:R6 A:R8 A:R15 A:R17 R15-17 R69 R78-82 | 13 | 10K |  |  | RES 1/16W 5% 0402 SMD
30 | A:R5 A:R9 A:R11-12 | 4 | 1K |  |  | RES 1/16W 5% 0402 SMD
31 | A:R16 R9 R18 R22-23 | 5 | 2K2 |  |  | RES 1/16W 5% 0402 SMD
32 | R3-8 R10 | 7 | 39 |  |  | RES 1/16W 5% 0402 SMD
33 | R20-21 | 2 | 56K |  |  | RES 1/16W 5% 0402 SMD
34 | A:R1 R13-14 R67 | 4 | 680 |  |  | RES 1/16W 5% 0402 SMD
35 | A:R13-14 R11 R24 | 4 | DNP |  |  | RES 1/16W 5% 0402 SMD
36 | R19 | 1 | 2K2 |  |  | RES 1/10W 1% 0603 SMD
37 | R27-50 R60 R74-75 R83 | 28 | 0 |  |  | RES 1/10W 5% 0603 SMD
38 | R84-86 | 3 | 100K |  |  | RES 1/10W 5% 0603 SMD
39 | R51-54 | 4 | 100m |  |  | RES 1/10W 5% 0603 SMD
40 | R61 | 1 | 1K |  |  | RES 1/10W 5% 0603 SMD
41 | R59 R71 | 2 | DNP |  |  | RES 1/10W 5% 0603 SMD
42 | R62 | 1 | 0 |  |  | RES 1/8W 5% 0805 SMD
43 | A:TP1-2 TP1-7 | 9 |  |  |  | Via, 20 ID, 40 OD (mil)
44 | A:C31 | 1 | 10n | 1812SC103KAT1A | 478-4735-1-ND | CAP CER 1.5KV 10% X7R 1812
45 | J8 | 1 |  | 1981584-1 | A97799CT-ND | USB micro AB Female USB2.0
46 | A:SW1 SW1 | 2 | 218-2LPST | 218-2LPST | CT2182LPST-ND | 2xSPST DIP switch SMT, half-pitch
47 | U5 | 1 | micro-SD | 2908-05WB-MG | 3M5607CT-ND | micro SD Connector+Ejector, 10 (8+2) positions, SMT-top
48 | X1 | 1 | 20MHz, 20ppm | 7B-20.000MEEQ-T | 887-1303-1-ND | 20MHz Crystal, 20ppm
49 | A:U5 | 1 |  | 93LC56C-I/SN | 93LC56C-I/SN-ND | IC EEPROM 2KBIT 3MHZ 8SOIC
50 | L5-6 | 2 | 60Ohm | BKP2125HS600-T | 587-1932-1-ND | FERRITE 3A 60OHM@100MHz 0805 SMD
51 | L3-4 | 2 | 220Ohm | BLM21PG221SN1D | 490-1054-1-ND | FERRITE 2A 220OHM@100MHz 0805 SMD
52 | SW2-3 | 2 | CAS-D20TA | CAS-D20TA | CASD20JCT-ND | Switch SPDT, 2 position
53 | D2 | 1 |  | CFSH05-20L TR | CFSH05-20L CT-ND | DIODE SCHOTTKY, 220mV@10mA, SOD882L
54 | J9 | 1 |  | DF40C-60DP-0.4V(51) | H11628CT-ND | 60pin connector - SMT, Hirose DF40C-60DP-0.4V(51)
55 | A:X1 | 1 | 12 MHz | ECS-120-20-30B-TR | XC1118CT-ND | CRYSTAL 12.000 MHZ 20PF SMD
56 | A:U4 | 1 |  | FT2232HL | 768-1024-1-ND | IC USB HS DUAL UART/FIFO 64-QFN
57 | A:L1-2 | 2 |  | HZ0805E601R-10 | 240-2399-1-ND | FERRITE 500MA 600 OHM 0805 SMD
58 | A:U6-8 A:U10 | 4 |  | ISO7220CD | 296-21953-1-ND | IC DGTL ISOLATOR 25MBPS 2CH 8SOIC
59 | J2-7 | 6 | 1x3 HDR | M22-2510305 | 952-1312-ND | Header Male; 1x3, 2mm pitch
60 | A:D1 D1 D3 | 3 |  | MBRM110ET1G | MBRM110ET1GOSCT-ND | DIODE SCHOTTKY 10V 1A POWERMITE
61 | U16 | 1 | NTA7002NT1G | NTA7002NT1G | NTA7002NT1GOSCT-ND | N-channel MOSFET 30V 0.154A
62 | U13 | 1 | OPA4350EA/250 | OPA4350EA/250 | OPA4350EACT-ND | IC OPAMP GP R-R 38MHZ QUAD 16DBQ
63 | U12 | 1 | REF5030IDGKT | REF5030IDGKT | 296-24501-1-ND | IC, 3.0V Vref, 0.05%, 8DGK
64 | A:U9 | 1 | 3-State Buffer | SN74ALVC244PWR | 296-5136-1-ND | 3-State Buffer, 2 elements x 4 bits
65 | U2 | 1 | SN74LVC2G07DBVR | SN74LVC2G07DBVR | 296-13494-1-ND | Buffer Line Driver, non-inverting, 32mA
66 | A:C3 | 1 | 47u | TCTP0J476M8R | 511-1682-1-ND | CAP TANT 20% 0805 6.3V
67 | C94 | 1 | 68u | TLJA686M010R1500 | 478-4925-1-ND | CAP TANT 10V 20% 1206
68 | U1 | 1 |  | TMS320F28379DZWT |  | MCU F2837x 337pin ZWT BGA
69 | A:U2 | 1 |  | TPD2E001DRLR | 296-21883-1-ND | IC ESD-PROT ARRAY 2CH SOT-5
70 | U6-11 | 6 | TPD4E001QDBVRQ1 | TPD4E001QDBVRQ1 | 296-39344-1-ND | TVS 4-ch UniDir Diode Array: VCC & GND prot, 11V brkdwn
71 | D4 | 1 | TPD4S012DRYR | TPD4S012DRYR | 296-24244-1-ND | 4-channel USB ESD Diode for USB-HS/USB OTG; 6SON
72 | U15 | 1 | TPS2051BDBVR | TPS2051BDBVR | 296-21265-1-ND | High-Side Power Distribution Switch
73 | U4 | 1 | TPS3702CX12DDCT | TPS3702CX12DDCT | 296-42074-1-ND | Volage Monitor, 1.2V, 5% or 10%
74 | U3 | 1 | TPS3702CX33DDCT | TPS3702CX33DDCT | 296-39651-1-ND | Volage Monitor, 3.3V, 5% or 10%
75 | U14 | 1 |  | TPS62420DRC | 296-25650-1-ND | IC Dual Step Down Converter, 2.25MHz, 600mA/1A
76 | A:U1 | 1 |  | TPS73033DBV | 296-17580-1-ND | IC LDO REG HI-PSRR 3.3V SOT23-5
77 | A:J1 | 1 |  | UX60-MB-5ST | H2959CT-ND | CONN RECEPT MINI USB2.0 5POS
78 | L1 | 1 | 2u2 | VLF3010AT-2R2M1R0 | 445-3215-1-ND | Inductor Power 2.2uH 1.0A SMD 20%
79 | L2 | 1 | 3u3 | VLF3010AT-3R3MR87 | 445-3216-1-ND | Inductor Power 3.3uH 0.87A SMD 20%
X | X | 1 | Sticker |  |  | Sticker with Serial Number (similar to F28M36 cCARD)
X | X | 6 | Jumpers |  |  | 2mm jumpers (SPN02SXCN-RC or similar)

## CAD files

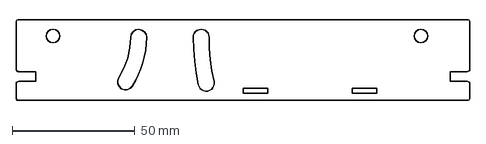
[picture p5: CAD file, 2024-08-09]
Hardware/mechanical/Test Jig/New Cuts/4Wire-Laser-Divider.dxf
185.0 x 33.0 mm

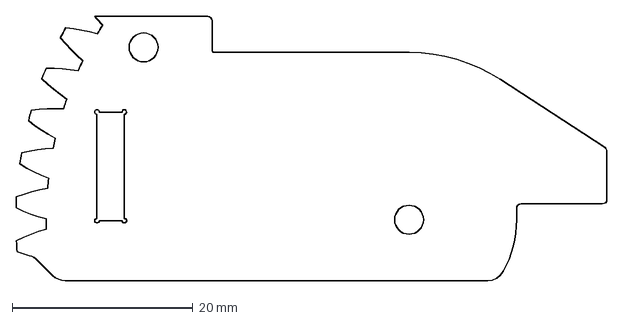
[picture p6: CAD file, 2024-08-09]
Hardware/mechanical/Test Jig/other/4wire-Small-Slot-Side.dxf
65.4 x 29.3 mm

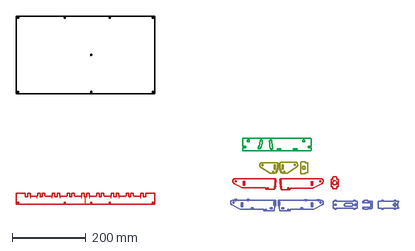
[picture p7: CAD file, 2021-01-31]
Hardware/mechanical/tida-010086-e3/4Wire Divider Holder Output.dxf
1036.3 x 527.4 mm

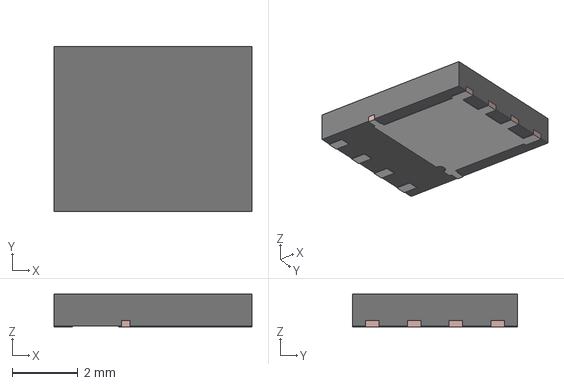
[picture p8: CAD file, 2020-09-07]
Hardware/schematics/Lion-IRVT/DNK0008A.stp
6.00 x 5.00 x 1.00 mm
FRAME
MOLD

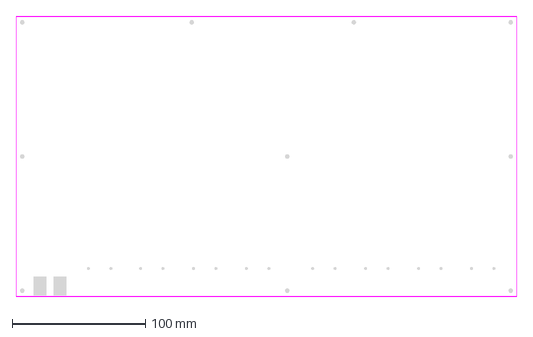
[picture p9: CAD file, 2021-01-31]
Hardware/schematics/TIDA-010086/XTIDA-010086.multilayer.DXF
375.3 x 210.3 mm

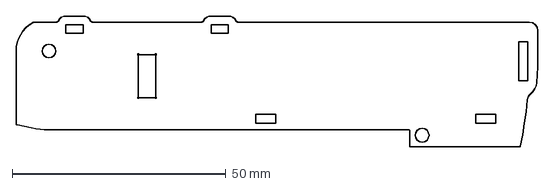
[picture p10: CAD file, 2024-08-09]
Hardware/mechanical/Test Jig/other/4wire-large-slot-inner.dxf
122.1 x 30.7 mm

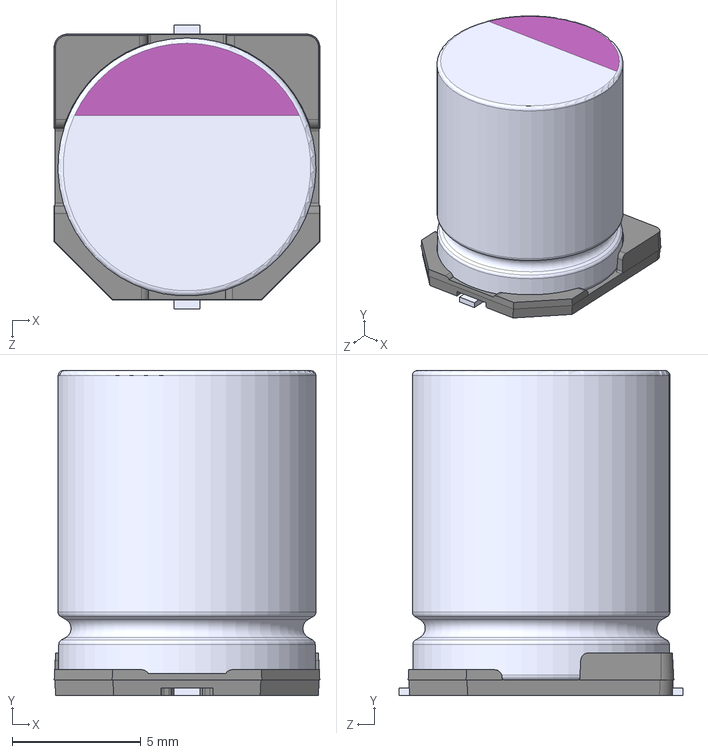
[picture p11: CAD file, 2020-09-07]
Hardware/schematics/Lion-IRVT/10 SIZE CODE F12.stp
10.3 x 12.6 x 11.0 mm

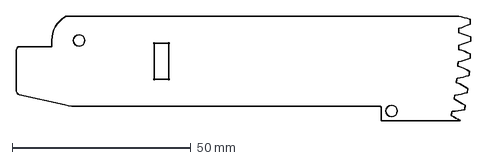
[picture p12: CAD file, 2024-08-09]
Hardware/mechanical/Test Jig/other/4wire-large-slot-side.dxf
127.1 x 29.3 mm

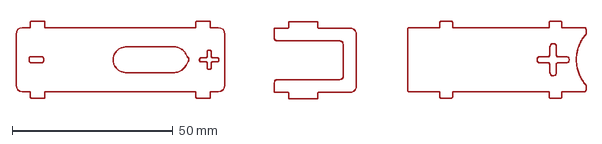
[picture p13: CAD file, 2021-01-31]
Hardware/mechanical/tida-010086-e3/2mm parts.dxf
177.4 x 24.2 mm

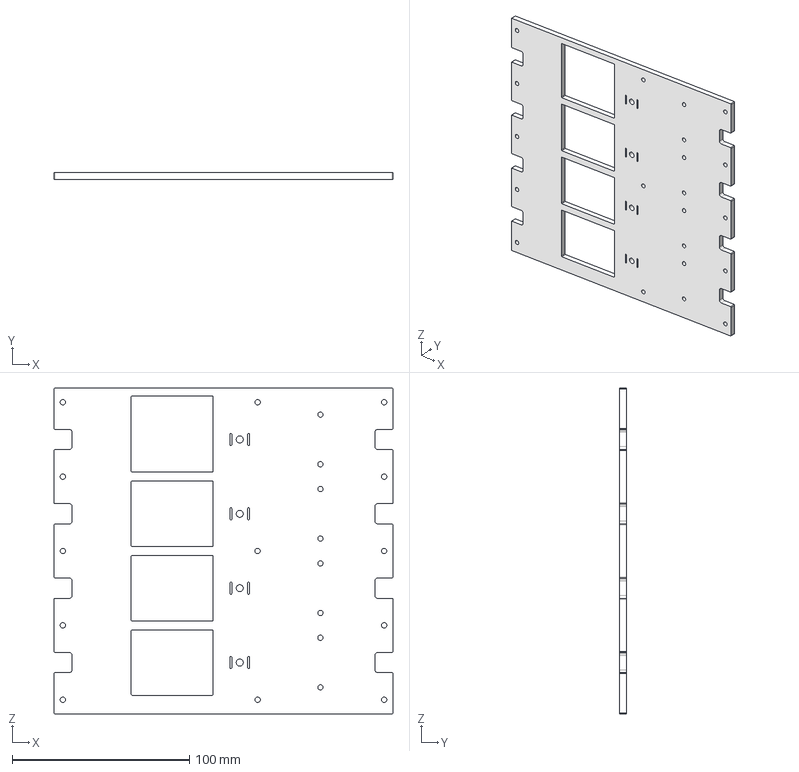
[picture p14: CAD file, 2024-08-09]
Hardware/mechanical/Test Jig/other/Laser-Base-x4.stp
191.5 x 4.00 x 184.0 mm

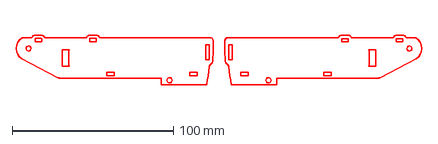
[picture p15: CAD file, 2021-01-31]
Hardware/mechanical/tida-010086-e3/4Wire Large Inner 2mm.dxf
251.4 x 30.7 mm

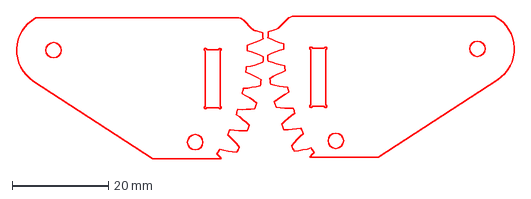
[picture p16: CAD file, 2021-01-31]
Hardware/mechanical/tida-010086-e3/4Wire Small 3mm.dxf
103.4 x 29.5 mm

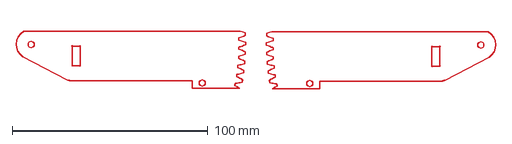
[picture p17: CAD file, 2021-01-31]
Hardware/mechanical/tida-010086-e3/4Wire Large Outer 4mm.dxf
245.0 x 29.5 mm

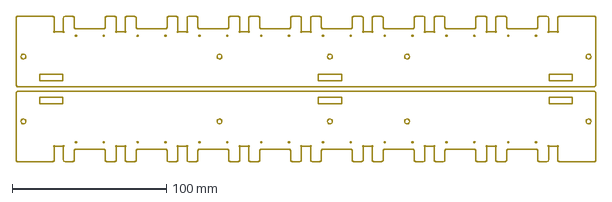
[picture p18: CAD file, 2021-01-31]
Hardware/mechanical/tida-010086-e3/holder bar 4mm.dxf
375.0 x 93.9 mm

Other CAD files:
Hardware/mechanical/tida-010086-e3/XTIDA-010086.DWG
Hardware/mechanical/tida-010086-e3/XTIDA-010086.multilayer.dwg
Hardware/mechanical/tida-010086-e3/bottom plate 4mm.dxf
Hardware/mechanical/tida-010086-e3/XTIDA-010086.mech.DWG
Hardware/mechanical/Test Jig/New Cuts/4Wire-Laser-Divider.dwg
Hardware/mechanical/Test Jig/other/4wire-Small-Slot-Side.dwg
Hardware/mechanical/Test Jig/other/4wire-large-slot-inner.dwg
Hardware/mechanical/Test Jig/other/4wire-large-slot-side.dwg
Hardware/mechanical/tida-010086-e3/2mm parts.dwg
Hardware/mechanical/tida-010086-e3/4Wire Divider Holder Output.dwg
Hardware/mechanical/tida-010086-e3/4Wire Large Inner 2mm.dwg
Hardware/mechanical/tida-010086-e3/4Wire Large Outer 4mm.dwg
Hardware/mechanical/tida-010086-e3/4Wire Small 3mm.dwg
Hardware/mechanical/tida-010086-e3/4Wire-Output.dwg
Hardware/mechanical/tida-010086-e3/4Wire-Output.dxf
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

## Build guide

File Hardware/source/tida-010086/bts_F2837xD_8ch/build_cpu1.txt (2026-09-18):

{
    "output": "\n**** Build of configuration 'cpu1' for project 'bts_F2837xD_8ch' ****\n\n\"C:\\\\ti\\\\ccs2101\\\\ccs\\\\utils\\\\bin\\\\gmake\" -k -j 4 all -r -O \n \nC2000 Compiler - building file: \"../bts_cpu1.c\"\n\"C:/ti/ccs2101/ccs/tools/compiler/ti-cgt-c2000_25.11.1.LTS/bin/cl2000\" -v28 -ml -mt --cla_support=cla1 --float_support=fpu32 --tmu_support=tmu0 --vcu_support=vcu2 -O3 --opt_for_speed=5 --fp_mode=relaxed --include_path=\"C:/sandbox/github/Lion-IRVT/Hardware/source/tida-010086/bts_F2837xD_8ch\" --include_path=\"C:/sandbox/github/Lion-IRVT/Hardware/source/tida-010086/bts_F2837xD_8ch/device\" --include_path=\"C:/ti/c2000/C2000Ware_DigitalPower_SDK_5_03_00_00/c2000ware/driverlib/f2837xd/driverlib\" --include_path=\"C:/sandbox/github/Lion-IRVT/Hardware/source/tida-010086/bts_F2837xD_8ch/libraries/sfra\" --include_path=\"C:/sandbox/github/Lion-IRVT/Hardware/source/tida-010086/bts_F2837xD_8ch/libraries/DCL\" --include_path=\"C:/sandbox/github/Lion-IRVT/Hardware/source/tida-010086/bts_F2837xD_8ch/libraries/SFO\" --include_path=\"C:/ti/c2000/C2000Ware_DigitalPower_SDK_5_03_00_00/libraries/sfra/include\" --include_path=\"C:/ti/c2000/C2000Ware_DigitalPower_SDK_5_03_00_00/libraries/sfra/gui/include\" --include_path=\"C:/ti/ccs2101/ccs/tools/compiler/ti-cgt-c2000_25.11.1.LTS/include\" --define=_TI_EABI_ --define=_DEBUG --define=CLA_DEBUG=1 --define=F28x_DEVICE --define=CPU1 --define=LARGE_MODEL --define=_FLASH -g --c99 --float_operations_allowed=32 --diag_suppress=10063 --diag_suppress=173 --diag_warning=225 --diag_wrap=off --display_error_number --quiet --abi=eabi -k --asm_listing --preproc_with_compile --preproc_dependency=\"bts_cpu1.d_raw\" --include_path=\"C:/sandbox/github/Lion-IRVT/Hardware/source/tida-010086/bts_F2837xD_8ch/cpu1/syscfg\"  \"../bts_cpu1.c\"\nFinished building: \"../bts_cpu1.c\"\n \nC2000 Linker - building target: \"bts_F2837xD_8ch_cpu1.out\"\n\"C:/ti/ccs2101/ccs/tools/compiler/ti-cgt-c2000_25.11.1.LTS/bin/cl2000\" -v28 -ml -mt --cla_support=cla1 --float_support=fpu32 --tmu_support=tmu0 --vcu_support=vcu2 -O3 --opt_for_speed=5 --fp_mode=relaxed --define=_TI_EABI_ --define=_DEBUG --define=CLA_DEBUG=1 --define=F28x_DEVICE --define=CPU1 --define=LARGE_MODEL --define=_FLASH -g --c99 --float_operations_allowed=32 --diag_suppress=10063 --diag_suppress=173 --diag_warning=225 --diag_wrap=off --display_error_number --quiet --abi=eabi -k --asm_listing -z -m\"bts_F2837xD_8ch_cpu1.map\" --heap_size=0x200 --stack_size=0x300 --warn_sections -i\"C:/ti/ccs2101/ccs/tools/compiler/ti-cgt-c2000_25.11.1.LTS/lib\" -i\"C:/ti/c2000/C2000Ware_DigitalPower_SDK_5_03_00_00/libraries/sfra/lib/\" -i\"C:/ti/c2000/C2000Ware_DigitalPower_SDK_5_03_00_00/c2000ware/libraries/calibration/hrpwm/F2837xD/lib/\" -i\"C:/ti/c2000/C2000Ware_DigitalPower_SDK_5_03_00_00/c2000ware/libraries/math/FPUfastRTS/c28/lib/\" -i\"C:/ti/ccs2101/ccs/tools/compiler/ti-cgt-c2000_25.11.1.LTS/include\" --reread_libs --diag_wrap=off --display_error_number --xml_link_info=\"bts_F2837xD_8ch_linkInfo.xml\" --ram_model -o \"bts_F2837xD_8ch_cpu1.out\" \"./bts.obj\" \"./bts_cpu1.obj\" \"./bts_hal.obj\" \"./com_cpu2.obj\" \"./led_driver.obj\" \"./registers.obj\" \"./device/F2837xD_CodeStartBranch.obj\" \"./device/device.obj\" \"./libraries/DCL/DCL_error.obj\" \"./libraries/sfra/sfra_gui_scicomms_driverlib.obj\" \"../2837xD_RAM_lnk_cpu1.cmd\" \"C:/ti/c2000/C2000Ware_DigitalPower_SDK_5_03_00_00/c2000ware/libraries/calibration/hrpwm/f2837xd/lib/SFO_v8_fpu_lib_build_c28_driverlib_eabi.lib\" \"C:/ti/c2000/C2000Ware_DigitalPower_SDK_5_03_00_00/c2000ware/driverlib/f2837xd/driverlib/ccs/Debug/driverlib_eabi.lib\" \"C:/ti/c2000/C2000Ware_DigitalPower_SDK_5_03_00_00/c2000ware/libraries/math/FPUfastRTS/c28/lib/rts2800_fpu32_fast_supplement_eabi.lib\" \"C:/ti/c2000/C2000Ware_DigitalPower_SDK_5_03_00_00/libraries/sfra/lib/sfra_f32_tmu_eabi.lib\"  -llibc.a \nFinished building target: \"bts_F2837xD_8ch_cpu1.out\"\n \n**** Build finished ****\n\n",
    "errors": [],
    "success": true
}

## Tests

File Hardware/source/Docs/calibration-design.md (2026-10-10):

# Slot Calibration — Design and Implementation Specification

Authoritative design for the externally-referenced, per-slot calibration process
across the C2000 BTS firmware, the ESP32 proxy, and the bench automation script.

This document is the contract for the **mathematics, the opcodes, the state
machine and the F-RAM layout**. Implementations must not deviate from those
without updating this file first.

> ### Addresses here are the v2.1 map, but §2.8 of the API spec is authoritative
>
> This document was written before the v2 reorder (2026-09-19) and the settings
> compression (2026-09-22), which moved every address in it. The addresses have
> since been brought forward: the calibration control block is **1008–1024**,
> its telemetry **1032–1064**, and the per-slot calibration group sits at
> `BTS_SET_BASE(ch) + 6` registers — byte address **408 + ch × 72**.
>
> This is a *design* document, so where an address appears it is illustrative.
> **For any address, read
> [`api-specification.md`](api-specification.md) §2.8**, which is verified
> against `registers.h` and is where a drift will be caught first. Everything
> else here — the two-point fit, the capture windows, the opcode and status-bit
> numbering, the validation limits and the F-RAM block layout — is current and
> is still the contract.

---

## 1. Goal

Replace the compile-time calibration constants in `bts_user_calibration.h` with a
runtime, externally-referenced two-point calibration performed per slot, using:

- an external DC bench supply as the voltage source and current source, and
- an external DMM (Agilent/Keysight, LAN/SCPI) as the reference instrument.

Both measurement paths are calibrated simultaneously from the same physical
stimulus:

| Path | Device | Resolution | Registers calibrated |
|---|---|---|---|
| External | ADS131M08 | 16-bit | `IoutGain/Offset_pu`, `IoutGain/Offset_A`, `VoutGain/Offset_pu`, `VoutGain/Offset_V` |
| Internal | F2837xD on-chip ADC | 12-bit @ 2.5 V ref | `F28V_Gain/Offset`, `F28I_Gain/Offset` |

Results are persisted to the FM24V10 F-RAM and reloaded at boot.

---

## 2. Existing behaviour that must be preserved

- `registers[]` is written **only** by CPU2. CPU1 publishes via `cpu1Status`
  under the `seq` seqlock. Calibration must not violate this.
- Register addresses are hard-coded by external hosts. **Never insert a register
  mid-map.** All new registers append above the current top (`eGroupSize` = 1032).
- The `BTS_*_BASE(ch)` macros are the only legal way to index a block.
- `--float_operations_allowed=32`: no doubles, use `strtof` not `atof`.
- A C28x byte is 16 bits; a `float` is 2 words. Anything crossing I2C/CAN/UART
  must be packed explicitly.

### 2.1 Facts that are easy to get wrong

These were each verified in source and each one invalidates an obvious guess:

1. **Calibration drives current, never voltage.** The build was CC-only
   when this design was written and is CC-CV now
   (`BTS_LAB_TYPE = BTS_LAB_CLOSED_LOOP_CCCV`), but calibration still only
   uses fixed *current*: the slot is driven into a bench supply that holds the
   voltage, which is what makes a current capture meaningful. A fixed-voltage
   calibration mode is deliberately not part of this design.

2. **The current sense side is never gain-corrected.** `ioutSense_pu =
   current_16b / 32768` (`bts.h:518`) — calibration is folded into the
   *setpoint* only (`bts.c:570`). The loop closes in raw-ADC per-unit space.
   This is precisely why `IoutGain_pu` (A→pu, for the reference) and
   `IoutGain_A` (pu→A, for reporting) are stored as a reciprocal pair.

3. **CPU1 does not see the new registers unless it is told to.**
   `BTS_HandleRegisterWrite()` (`bts_cpu1.c:568, 576-577`) only decodes indices
   below `eCh0_CurrentAcc` and inside the calibration block. Everything else —
   including `eCalibrationMode` at index 244 — has its `IPC_FLAG0` acked and
   silently discarded. The calibration block (1008+) falls in the same hole and
   **must be in the decode explicitly**, or every calibration command will
   be accepted by CPU2 and quietly ignored by CPU1.

4. **F-RAM writes never happen in an ISR.** Writing `eCalibrationMode = 2.0f`
   sets `calibrationSavePending` (`com_cpu2.c:1974-1976`) and the idle-loop
   `BTS_serviceDeferredWork()` (`com_cpu2.c:2076-2090`) performs the save. The
   comment at `com_cpu2.c:1961-1967` says this is deliberate. `CAL_CMD_COMPUTE_SAVE`
   must use the same deferred pattern.

5. **Status word ceiling is bit 23, not 31.** The word reaches the host as a
   `float32`, whose 24-bit significand makes integers exact only to bit 23
   (`registers.h:353-356`). Bits 12–23 are free; never go past 23.

6. `eCalibrationMode` decodes **only** exact float `2.0f`, with no tolerance, and
   is never cleared or acknowledged — there is no "save complete" indication
   today. The new `eCalStatus` bit 7 supplies one.

---

## 3. Bugs that must be fixed as part of this work

### 3.1 F-RAM channel 4 collides with the global voltage block

`CAL_EEPROM_BYTES = 2 * sizeof(BTS_channelCalibration)` = 64 wire bytes, and
`writeEEPROM()` uses `eepromAddr = channel * CAL_EEPROM_BYTES`
(`com_cpu2.c:747-754`). Channel 4 therefore occupies `0x0100`–`0x013F`, and
`EEPROM_GLOBAL_V_ADDR` is `0x0100`–`0x010F` (`com_cpu2.c:91`). They overlap on
channel 4's `header`, `dateTime`, `MinCellTemp` and `MaxCellTemp`.

The failure is invisible, which is why it has survived: `saveAllCalibration()`
iterates 0→7, so channel 0 writes the globals to `0x0100` and **channel 4 then
overwrites them**. At next boot `loadCalibration()` reads `0x0100` as globals,
gets channel 4's header and temps reinterpreted as floats,
`validateGlobalVoltages()` rejects them, and 9/10/15/16 V defaults are silently
installed. Channel 4's own block still validates, so nothing looks wrong — the
global thresholds simply never persist.

**Fix:** a fixed, generous stride with the globals moved well clear. The FM24V10
is 128 KiB, so space is not a constraint:

```c
#define CAL_FRAM_STRIDE_BYTES   128U        /* per channel, fixed, not sizeof-derived */
#define CAL_FRAM_BASE           0x0000U     /* ch N at BASE + N*STRIDE, ends 0x03FF */
#define EEPROM_GLOBAL_V_ADDR    0x0400U     /* was 0x0100 */
```

A fixed stride also decouples the wire layout from `sizeof`, so adding struct
fields no longer silently moves every channel's block.

### 3.2 `Isense_A` / `Vsense_V` are computed but never published

`BTS_monitor_Iout_Vout()` (`bts_cpu1.c:628-631`) produces the ADS131M08
engineering values, but nothing reads them — not `publishStatusToCpu2()`, not
`cpu1Status`, not `canData`, not `registers[]`. The 16-bit converter's readings
are dead, and every host interface today is showing the **12-bit internal ADC**
values via `eChX_CellVoltage` / `eChX_CellCurrent`.

This is the opposite of what the register-map naming suggests, and it must be
fixed before calibration: the process captures both paths simultaneously and
needs both visible.

### 3.3 CC/CV status bits — done

`ctrlMode_logic` is now copied into `status[].constCurrent/constVoltage`, and
under the CC-CV build it genuinely moves, so bits 6 and 7 track the loop. Both
read 0 while a slot is not running, because an idle loop sits in CC and would
otherwise show every stopped slot as "in CC".

> Bits 2 (`FINISHED`), and the dead stats accumulators at 320/324/328/332, are
> also never written. Those are **out of scope** here — noted so the next reader
> does not mistake them for calibration regressions.

---

## 4. Register map additions

All addresses are byte addresses; index = address / 4. Appended contiguously
above `eGroupSize`, which is **1000** in the current map. Update `registers.h`
enum, `NUM_*` counts, `TOTAL_REGISTERS`, `regConfig[]` and `uartRegConfig[]`
**together** — the tables are sized `TOTAL_REGISTERS` and must stay
index-aligned.

The addresses below are **as built**, re-verified against `registers.h`. They
are not the ones this section originally proposed: the v2 reorder (2026-09-19)
and the settings compression (2026-09-22) both moved them.

### 4.1 Calibration control block (unit-level, 5 registers)

Only one slot calibrates at a time, so this block is unit-scoped rather than
per-slot. That is a deliberate RAM decision — see §9.

| Addr | Enum | Access | Meaning |
|---|---|---|---|
| 1008 | `eCalSlot` | RW | Slot under calibration, 0–7. 255 = none. |
| 1012 | `eCalCommand` | RW | Command opcode, see §5. Write triggers action. |
| 1016 | `eCalArgument` | RW | Float payload for the command. Write **before** the opcode. |
| 1020 | `eCalStatus` | RO | Progress bitfield, see §5.2. |
| 1024 | `eCalResult` | RO | Result code of the last command, see §5.3. |

### 4.2 Calibration live telemetry (unit-level, 9 registers)

Live values for the slot named by `eCalSlot`, so the operator can watch the
calibration converge. Zero when no slot is selected.

One register separates this block from §4.1: `eWatchdogRemaining_s` (**1028**),
the live host-watchdog countdown. It is not calibration telemetry, but it sits
inside the burst below and a mirror that omits it reads every float here one
register low — see §2.11 of
[`api-specification.md`](api-specification.md) for the defect that caused.

| Addr | Enum | Access | Meaning |
|---|---|---|---|
| 1032 | `eCalAdsV_pu` | RO | ADS131M08 voltage, per-unit (raw, pre-gain) |
| 1036 | `eCalAdsI_pu` | RO | ADS131M08 current, per-unit (raw, pre-gain) |
| 1040 | `eCalAdsV_V` | RO | ADS131M08 voltage, volts (post-gain) |
| 1044 | `eCalAdsI_A` | RO | ADS131M08 current, amps (post-gain) |
| 1048 | `eCalF28V_pu` | RO | Internal ADC voltage, per-unit (raw, pre-gain) |
| 1052 | `eCalF28I_pu` | RO | Internal ADC current, per-unit (raw, pre-gain) |
| 1056 | `eCalF28V_V` | RO | Internal ADC voltage, volts (post-gain) |
| 1060 | `eCalF28I_A` | RO | Internal ADC current, amps (post-gain) |
| 1064 | `eCalTemp_C` | RO | Live cell temperature of the slot under calibration |

1064 is the top of the unit block. The **slot tuning** registers (DCL biquad
coefficients, 1068–1116) sit above it; the map does not end at 1064.

"Per-unit (raw, pre-gain)" is the normalised converter reading **before** any
calibration gain/offset is applied — this is the quantity the two-point maths
consumes, and it must not be silently pre-scaled.

- ADS path: `sum / (BTS_senseAverageFactor * 32768.0)`
- Internal path: `(sum / (BTS_f28AverageFactor * 4096.0)) * 2.5`

The internal-path quantity is in volts-at-the-pin, matching how
`BTS_monitor_Iout_Vout()` scales it (`bts_cpu1.c:632-635`). Keep that definition
exactly — the gain/offset pair is defined against it.

### 4.3 Per-slot external ADC engineering values (16 registers)

Fixes §3.2. **Built differently from the proposal below.** Rather than a
separate region above the unit block, the two values were folded into each
slot's existing runtime block, where the rest of that slot's live measurements
already are:

| Addr | Enum | Access | Meaning |
|---|---|---|---|
| `BTS_RT_BASE(ch)` + 12 | `eChX_SenseVoltage` | RO | `Vsense_V`, ADS131M08 volts |
| `BTS_RT_BASE(ch)` + 16 | `eChX_SenseCurrent` | RO | `Isense_A`, ADS131M08 amps |

With the runtime stride of 48 bytes that is 12/16 for slot 1 through 348/352
for slot 8. There is no `BTS_SENSE_BASE(ch)` — the runtime base macro covers
them, and a reader looking for a separate sense region will not find one.

**Total registers: 280**, top byte address **1116**.

### 4.4 Status bits

Bits 0–11 are in use (`registers.h:372-383`). Append:

```c
#define BTS_STATUS_CALIBRATING     12U  /* slot is in the calibration state   */
#define BTS_STATUS_CAL_V_VALID     13U  /* voltage calibration computed & OK  */
#define BTS_STATUS_CAL_I_VALID     14U  /* current calibration computed & OK  */
```

Bits 13/14 drive the green ticks on the ESP32 display. They are set from the
persisted calibration validity, not merely from the in-session capture, so a slot
calibrated in an earlier session still shows its ticks.

Extend `status[]`, `publishStatusToCpu2()` and the ESP32 `bts_regs.h` mirror
(which currently stops at bit 7 — note `tools/ble_verify.py` already knows 12
names; reconcile all three).

### 4.5 Mode register

`eChX_Mode` bit 2 (`0x04`) = enter calibration. Writing it is equivalent to
`eCalSlot = X; eCalCommand = CAL_CMD_ENTER`. Both entry points route to the same
handler so the one-slot-at-a-time rule is enforced in one place.

---

## 5. Command protocol

Write `eCalArgument` first, then `eCalCommand`. The command is consumed on write,
`eCalResult` is updated synchronously, and `eCalCommand` self-clears to 0.

### 5.1 Opcodes

| Code | Name | Argument | Action |
|---|---|---|---|
| 0 | `CAL_CMD_NONE` | — | idle |
| 1 | `CAL_CMD_ENTER` | — | Put `eCalSlot` into the calibration state. Force-exits calibration on every other slot. Rejected if any slot is running a test. |
| 2 | `CAL_CMD_EXIT` | — | Zero the reference, disable the slot, leave calibration. Captures discarded unless already saved. |
| 3 | `CAL_CMD_CAPTURE_VOLTAGE` | measured volts | Sample both paths. Classify by ADS pu: `< 0.2` → low point, `> 0.8` → high point. Anything between is rejected with `CAL_ERR_PU_RANGE`. |
| 4 | `CAL_CMD_ZERO_CURRENT` | — | With the converter disabled and no current flowing, capture the zero-current pu of both current paths as the low point at 0.0 A. |
| 5 | `CAL_CMD_SET_FIXED_CURRENT` | pu setpoint | Put the slot into fixed-current **DISCHARGE** at the given uncalibrated pu. 1.0 pu ≈ 10 A (`BTS_ISET_MAX_A`), so 0.25 pu ≈ 2.5 A. Clamped, see §7. |
| 6 | `CAL_CMD_CAPTURE_CURRENT` | measured amps (magnitude) | Sample both current paths, store as the high point against the supplied magnitude. |
| 7 | `CAL_CMD_COMPUTE_SAVE` | — | Run the two-point maths (§6), validate, write F-RAM, reload into CPU1 via IPC. |
| 8 | `CAL_CMD_CLEAR` | — | Discard all in-session captures; stay in calibration. |

`CAL_CMD_CAPTURE_VOLTAGE` requires two captures on opposite sides before
`COMPUTE_SAVE` will compute a voltage result. Likewise current needs the zero
point plus one loaded point. `COMPUTE_SAVE` computes and saves whichever of the
two (voltage / current) is complete, and reports partial completion rather than
failing outright.

### 5.2 `eCalStatus` bitfield

| Bit | Meaning |
|---|---|
| 0 | Calibration active |
| 1 | Voltage low point captured |
| 2 | Voltage high point captured |
| 3 | Current zero point captured |
| 4 | Current loaded point captured |
| 5 | Voltage calibration computed and valid |
| 6 | Current calibration computed and valid |
| 7 | Written to F-RAM |
| 8 | Fixed-current mode currently driving |
| 9 | Last command failed (see `eCalResult`) |

### 5.3 `eCalResult` codes

`0` OK · `1` busy/another slot active · `2` slot running a test · `3` slot
disabled by strap or not a group leader · `4` pu outside the required window ·
`5` insufficient captures · `6` computed gain failed validation · `7` F-RAM write
failed · `8` argument out of range · `9` not in calibration state.

---

## 6. Two-point mathematics

The existing compile-time form in `bts_user_calibration.h:40-53` is the reference
and must be reproduced exactly so that runtime and compile-time results agree.

### 6.1 Voltage — external (ADS131M08)

Points `(pu_lo, V_lo)` and `(pu_hi, V_hi)`:

```
VoutGain_pu   = (pu_hi - pu_lo) / (V_hi - V_lo)
VoutOffset_pu = pu_lo - V_lo * VoutGain_pu
VoutGain_V    = 1.0 / VoutGain_pu
VoutOffset_V  = -VoutOffset_pu / VoutGain_pu
```

### 6.2 Voltage — internal (on-chip ADC)

Let `x = (sum / (BTS_f28AverageFactor * 4096.0)) * 2.5`, captured at the same two
instants as above, giving `(x_lo, V_lo)` and `(x_hi, V_hi)`:

```
F28V_Gain   = (V_hi - V_lo) / (x_hi - x_lo)
F28V_Offset = V_lo - x_lo * F28V_Gain
```

This inverts `CellVoltage_V = x * F28V_Gain + F28V_Offset` (`bts_cpu1.c:633`).

### 6.3 Current — external (ADS131M08)

Points `(pu_zero, 0.0)` and `(pu_hi, I_hi)`:

```
IoutGain_pu   = (pu_hi - pu_zero) / (I_hi - 0.0)
IoutOffset_pu = pu_zero
IoutGain_A    = 1.0 / IoutGain_pu
IoutOffset_A  = -IoutOffset_pu / IoutGain_pu
```

### 6.4 Current — internal (on-chip ADC)

With `x` defined as in §6.2 on the cell-current channel:

```
F28I_Gain   = (I_hi - 0.0) / (x_hi - x_zero)
F28I_Offset = -x_zero * F28I_Gain
```

### 6.5 Sign convention

Calibration current flows in **discharge**, which the control loop represents
with `direction_coeff = -1`. The operator enters the DMM reading as a
**magnitude**. The firmware applies the discharge sign internally so the stored
gain matches the running convention. Document this in the README — entering a
signed value is the single easiest way to invert a slot's current reading.

### 6.6 Guard conditions

Reject and return `CAL_ERR_PU_RANGE` / `CAL_ERR_VALIDATE` if:

- the two points are insufficiently separated (`|V_hi - V_lo| < 1.0 V`,
  `|I_hi| < 0.5 A`),
- any computed gain is zero, denormal, NaN or Inf,
- a computed gain falls outside the validation window in §8.

---

## 7. Calibration state and safety

`BTS_updateReference()` (`bts.c:557-605`) currently selects calibration behaviour
with the compile-time `BTS_CALIBRATION_ENABLED` / `BTS_CALIBATION_MODE` macros,
globally for all channels. **Convert this to a per-channel runtime state.** The
`ioutCal_pu` / `voutCal_pu` fields already exist in `BTS_userInput`
(`registers.h:532-533`) and are the right vehicle.

Add `volatile uint16_t calState;` to `BTS_userInput` (0 = normal, 1 = calibration
idle, 2 = calibration fixed-current). In `BTS_updateReference()`:

- `calState == 0` → existing normal-mode arithmetic, unchanged.
- `calState == 1` → `enable_logic = 0`, references zeroed. Measurement still runs.
- `calState == 2` → `ioutRef_pu = ioutCal_pu`, `voutRef_pu = 1.0`,
  `direction_logic = 0` (discharge), `direction_coeff = -1.0`.

The `BTS_CALIBRATION_ENABLED` macro path is removed; keep the header's
per-channel constants as boot defaults only.

### Mandatory safety rules

These are not optional and must be visible in code review:

1. **Trips stay armed.** CMPSS over-current and GPIO trip zones are never
   disabled, masked or re-thresholded during calibration. A trip exits
   calibration immediately and zeroes the reference.

   > **Bench warning.** The hardware over-current trips are enabled (±9.5 A,
   > above the software check's ±8 A) and the path has been seen to latch on
   > hardware — but the **level** has never been tested against a real
   > over-current. Calibration drives real current into an external supply, so
   > **do not run this procedure unattended**, and set the supply's own
   > current limit as the protection you trust.

2. **Fixed-current pu is clamped.** Reject `CAL_CMD_SET_FIXED_CURRENT` with
   argument `< 0.0` or `> 0.8` pu (≈8 A). Returns `CAL_ERR_ARG`.
3. **Min-voltage cutout bypass is scoped.** It applies only to the slot in
   `calState == 2`, and only while it is. Every other slot keeps its cutout.
   Note the guard is on the **input bus** voltage, not cell voltage, and it is
   enforced in two places — at mode-write time (`bts_cpu1.c:472-485`) and again
   at 10 Hz in `C1()` (`bts_cpu1.c:815-830`). **Both** must honour the exemption,
   or the periodic guard will stop the slot mid-calibration a fraction of a
   second after it starts.
4. **One slot only.** `CAL_CMD_ENTER` force-exits calibration on all other slots
   before entering the requested one.
5. **Not while testing.** `CAL_CMD_ENTER` is rejected if any slot is running a
   charge/discharge test.
6. **Dead-man timeout.** If `calState == 2` and no calibration command has been
   received for **120 s**, auto-exit to `calState == 1` and zero the reference.
   A bench supply left driving an unattended slot is the main physical risk in
   this whole procedure; this is the mitigation.
7. **Exit is always safe.** `CAL_CMD_EXIT`, a trip, a host disconnect timeout or
   a unit-state change all zero the reference before changing state.
8. **Group followers are excluded.** A slot that is not a group leader has no
   control loop of its own (`bts_cpu1.c:464-466`). Reject `CAL_CMD_ENTER` on a
   follower or a strap-disabled slot with `CAL_ERR_SLOT_UNAVAILABLE`, and do not
   propagate calibration state to followers the way `modeCallback()` propagates
   a normal start.

---

## 8. Persistence

### 8.1 Struct

Extend `BTS_channelCalibration` with validity and integrity fields:

```c
uint32_t calFlags;   /* bit0 voltage cal valid, bit1 current cal valid,
                        bit2 externally referenced (vs compiled default) */
uint32_t crc32;      /* over all preceding fields, little-endian word order */
```

Place them at the **end** so the existing field offsets are unchanged, and bump
the header magic so pre-change F-RAM images are rejected rather than
misinterpreted. With the fixed 128-byte stride from §3.1 there is ample room.

The header is a **two-field** word — magic in the high half, channel in the low
half (`registers.h:685-688`):

```c
#define BTS_CAL_HEADER          0xA5CC0000UL   /* -> 0xA5CD0000 for this revision */
#define BTS_CAL_HEADER_MASK     0xFFFF0000UL
#define BTS_CAL_CHANNEL_MASK    0x0000FFFFUL
#define BTS_CAL_MAKE_HEADER(ch) (BTS_CAL_HEADER | ((uint32_t)(ch) & BTS_CAL_CHANNEL_MASK))
```

> The skill reference doc describes this as `0xA5CC | channel`. That form is
> **wrong** and aliases for channels ≥ 4 — the code comment at `registers.h:683-684`
> calls this out explicitly. Use the masked two-field form above.

Bumping the magic to `0xA5CD0000` means every slot falls back to compiled
defaults on the first boot after this change, and must be recalibrated. That is
the intended behaviour: the pre-change images have an unknown-good channel 4 and
no `calFlags`.

### 8.2 Validation

`validateCalibration()` (`com_cpu2.c:774-792`) currently checks only the header,
temperature window and the F28 gains — the Iout/Vout gains are **not validated at
all**. Add windows derived from the known-good compile-time values
(`IoutGain_pu ≈ 0.100`, `VoutGain_pu ≈ 0.203`):

| Field | Min | Max |
|---|---|---|
| `IoutGain_pu` | 0.05 | 0.20 |
| `VoutGain_pu` | 0.10 | 0.40 |
| `F28V_Gain`, `F28I_Gain` | 0.5 | 2.0 |
| `F28V_Offset` | −1.0 | 1.0 |
| `F28I_Offset` | −2.0 | 2.0 |

Also require `IoutGain_A ≈ 1/IoutGain_pu` and `VoutGain_V ≈ 1/VoutGain_pu` to
within 0.1 %, catching a partially-written block.

### 8.3 Boot

`loadCalibration()` sets status bits 13/14 per channel from the persisted
`calFlags`, so the display ticks survive a power cycle. Unchanged otherwise: one
`BTS_IPC_FLAG_CAL_RELOAD` after the whole file is populated.

> Regression guard: `BTS_initUserVariables()` must keep seeding `F28V_Gain`,
> `F28V_Offset`, `F28I_Gain`, `F28I_Offset` from the compiled defaults. Those are
> IPC-only values and a missed one-shot reload previously left them at 0.0,
> producing a silent 0.0 V on every slot.

---
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

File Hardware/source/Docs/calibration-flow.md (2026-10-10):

# Calibration Flow Diagrams

Diagrams for the per-slot calibration feature. The authoritative definitions
are in [`calibration-design.md`](calibration-design.md); these render its
sections 5, 7 and 12 visually. The operator procedure is in
[`README.md`](README.md).

---

## 1. Operator process flow

Design doc section 12. One pass per slot; the script walks slots 1–8.

```mermaid
flowchart TD
    START([Start calibrate.py]) --> CFG[/"Configure: DMM IP, SCPI port, BLE address<br/>persisted to calibrate.ini"/]
    CFG --> DMM["Connect DMM over TCP 5025<br/>*IDN? verified, *RST, *CLS"]
    DMM --> DMMOK{Model<br/>supported?}
    DMMOK -->|no| ABORT([Abort])
    DMMOK -->|yes| BLE["Connect BLE: BTS-Tester<br/>check chars 000b / 000c present"]
    BLE --> SLOT{{"For each slot N in 1..8"}}

    SLOT --> WIRE[/"PROMPT: connect DC supply and DMM<br/>across slot N, DMM in PARALLEL"/]
    WIRE --> ENTER["CAL_CMD_ENTER (slot N)"]
    ENTER --> ENTOK{result<br/>== 0?}
    ENTOK -->|no| FAILSLOT["Report eCalResult as text<br/>CAL_CMD_EXIT"]
    ENTOK -->|yes| VLOW

    subgraph VOLT ["VOLTAGE PHASE — DMM in parallel"]
        VLOW[/"PROMPT: set supply to ~0.85 V"/] --> VLOWW{"live ADS pu<br/>&lt; 0.2 ?"}
        VLOWW -->|no, adjust| VLOWW
        VLOWW -->|yes| VLOWR["DMM: CONF:VOLT:DC, READ? -> V_lo"]
        VLOWR --> VLOWC["CAL_CMD_CAPTURE_VOLTAGE (V_lo)<br/>status bit 1"]
        VLOWC --> VHI[/"PROMPT: raise supply to ~4.25 V"/]
        VHI --> VHIW{"live ADS pu<br/>&gt; 0.8 ?"}
        VHIW -->|no, adjust| VHIW
        VHIW -->|yes| VHIR["DMM: READ? -> V_hi"]
        VHIR --> VHIC["CAL_CMD_CAPTURE_VOLTAGE (V_hi)<br/>status bit 2"]
    end

    VHIC --> IZERO

    subgraph CURR ["CURRENT PHASE — DMM in series"]
        IZERO[/"PROMPT: supply output OFF,<br/>break the slot current path"/] --> IZC["CAL_CMD_ZERO_CURRENT<br/>status bit 3"]
        IZC --> ILOAD[/"PROMPT: DMM into SERIES, supply ~3.7 V,<br/>ITS current limit 3 A, output ON"/]
        ILOAD --> ISET["CAL_CMD_SET_FIXED_CURRENT (0.25 pu)<br/>status bit 8 — slot now driving ~2.5 A"]
        ISET --> SETTLE["settle ~2 s"]
        SETTLE --> IREAD["DMM: CONF:CURR:DC, READ? -> I_hi"]
        IREAD --> IMAG["take |I_hi| — MAGNITUDE<br/>firmware applies the discharge sign"]
        IMAG --> ICAP["CAL_CMD_CAPTURE_CURRENT (|I_hi|)<br/>status bit 4"]
    end

    ICAP --> SAVE["CAL_CMD_COMPUTE_SAVE<br/>two-point maths, validate,<br/>F-RAM write, IPC reload<br/>status bits 5, 6, 7"]
    SAVE --> SAVEOK{"bit 7 set?"}
    SAVEOK -->|no| FAILSLOT
    SAVEOK -->|yes| EXIT["CAL_CMD_EXIT — reference zeroed"]
    EXIT --> VERIFY["Read slot status bits 13 / 14<br/>both set = both green ticks"]
    VERIFY --> TABLE["Print before/after gain table"]
    TABLE --> MORE{More<br/>slots?}
    FAILSLOT --> MORE
    MORE -->|yes| SLOT
    MORE -->|no| REPORT["Write JSON report"]
    REPORT --> DONE([Done])

    classDef prompt fill:#fff4e0,stroke:#d08a2a,color:#000
    classDef danger fill:#ffe3e3,stroke:#c0392b,color:#000
    class WIRE,VLOW,VHI,IZERO,ILOAD prompt
    class ISET,SETTLE,IREAD danger
```

The red-tinted steps are the only ones where the slot is driving current.
Everything from `CAL_CMD_SET_FIXED_CURRENT` to `CAL_CMD_COMPUTE_SAVE` runs with
roughly 2.5 A flowing — this is the window that must not be left unattended.
The hardware trips are armed throughout, but their level has not been tested
against a real over-current, so the supply's current limit is the protection
to rely on.

---

## 2. Per-slot calibration state machine

Design doc section 7. `calState` is a new field in `BTS_userInput`, evaluated
every millisecond in `BTS_updateReference()`.

```mermaid
stateDiagram-v2
    direction TB

    [*] --> Normal

    state "calState = 0 — NORMAL" as Normal
    state "calState = 1 — CAL IDLE" as CalIdle
    state "calState = 2 — CAL FIXED CURRENT" as CalDrive

    Normal: Existing reference arithmetic, unchanged
    Normal: ioutRef_pu = iref_A * IoutGain_pu + IoutOffset_pu
    Normal: Slot runs charge / discharge tests normally

    CalIdle: enable_logic = 0, references zeroed
    CalIdle: Measurement still running — telemetry is live
    CalIdle: Voltage captures happen here
    CalIdle: LED flashes white

    CalDrive: ioutRef_pu = ioutCal_pu
    CalDrive: voutRef_pu = 1.0
    CalDrive: direction_logic = 0, direction_coeff = -1.0 (DISCHARGE)
    CalDrive: Min-voltage cutout bypassed for THIS slot only
    CalDrive: 120 s dead-man timer running

    Normal --> CalIdle : CAL_CMD_ENTER or eChX_Mode bit 2<br/>force-exits every other slot<br/>rejected if any slot is testing
    CalIdle --> CalDrive : CAL_CMD_SET_FIXED_CURRENT (pu)<br/>0.0 to 0.8 pu, else CAL_ERR_ARG<br/>status bit 8 set

    CalDrive --> CalIdle : CAL_CMD_CAPTURE_CURRENT<br/>then setpoint released
    CalDrive --> CalIdle : dead-man timeout — 120 s<br/>with no calibration command<br/>reference zeroed
    CalDrive --> Normal : TRIP — CMPSS or GPIO<br/>reference zeroed immediately
    CalDrive --> Normal : CAL_CMD_EXIT
    CalDrive --> Normal : host disconnect timeout<br/>or unit state change

    CalIdle --> Normal : CAL_CMD_EXIT<br/>captures discarded unless already saved
    CalIdle --> Normal : TRIP
    CalIdle --> Normal : host disconnect / unit state change

    CalIdle --> CalIdle : CAL_CMD_CAPTURE_VOLTAGE<br/>pu below 0.2 is the low point,<br/>above 0.8 the high point,<br/>between them CAL_ERR_PU_RANGE
    CalIdle --> CalIdle : CAL_CMD_ZERO_CURRENT
    CalIdle --> CalIdle : CAL_CMD_COMPUTE_SAVE<br/>deferred F-RAM write from the idle loop
    CalIdle --> CalIdle : CAL_CMD_CLEAR<br/>discard captures, stay in calibration

    note right of CalDrive
        Trips are NEVER disabled, masked or
        re-thresholded during calibration.
        A trip always wins and always exits.
    end note

    note left of CalIdle
        One slot at a time. Group followers and
        strap-disabled slots are refused with
        CAL_ERR_SLOT_UNAVAILABLE.
    end note
```

### Exit paths, and what each guarantees

| Exit | Trigger | Reference zeroed | State after |
|---|---|---|---|
| Commanded | `CAL_CMD_EXIT` | yes, before the state change | Normal |
| Trip | CMPSS or GPIO trip zone | yes, immediately | Normal |
| Dead-man | 120 s with no calibration command in `calState == 2` | yes | Cal idle |
| Host loss | BLE/HTTP disconnect timeout | yes | Normal |
| Unit state | Input bus leaves its window | yes | Normal |

Every path zeroes the reference **before** it changes state. There is no
ordering in which the slot is left driving current with nothing supervising it.

---

## 3. One capture, end to end

What happens between the script calling `CAL_CMD_CAPTURE_VOLTAGE` and the
result coming back. The measurement path is the interesting half: the value
being captured originates on CPU1 and has already travelled the other way.

```mermaid
sequenceDiagram
    autonumber
    participant OP as Operator
    participant PY as calibrate.py
    participant DMM as Keysight DMM<br/>SCPI port 5025
    participant BLE as BLE / NimBLE<br/>ble_svc.c
    participant ESP as ESP32<br/>bts_link.c
    participant C2 as C2000 CPU2<br/>com_cpu2.c
    participant C1 as C2000 CPU1<br/>bts_cpu1.c
    participant HW as ADS131M08 +<br/>on-chip ADC

    Note over C1,HW: Measurement path — free-running, independent of any capture
    loop every control period
        HW->>C1: 16-bit sample pair
        C1->>C1: BTS_monitor_Iout_Vout()<br/>average, apply current gain/offset
        C1->>C2: cpu1Status (CPU1TOCPU2RAM)<br/>seq++ guards a torn read
        C2->>C2: mirror into registers[]<br/>CPU2 is the only writer
    end

    Note over OP,DMM: Capture begins
    OP->>PY: supply set to ~0.85 V
    PY->>BLE: read char e5f1000c (cal status)
    BLE-->>PY: ble_cal_status_t, little-endian
    PY->>PY: check ADS pu < 0.2, else keep prompting

    PY->>DMM: CONF:VOLT:DC AUTO
    PY->>DMM: READ?
    DMM-->>PY: 0.849683

    PY->>BLE: write char e5f1000b<br/>{opcode=3, slot=1, rsvd, arg=0.849683f}<br/>packed LITTLE-endian
    BLE->>ESP: bts_link_cal_capture_voltage(slot, v)

    Note over ESP,C2: I2C wire format is BIG-endian — opposite to BLE
    ESP->>C2: write eCalArgument (1016) = 0.849683f<br/>S 0x50+W | 0x03 0xF8 | b0 b1 b2 b3 | P
    ESP->>C2: write eCalCommand (1012) = 3.0f
    C2->>C2: i2cSlaveISR -> applyHostRegisterWrite()
    C2->>C1: ipcMsg{regAddr, value} + IPC_FLAG0

    Note over C1: The 1008+ block MUST be in the<br/>BTS_HandleRegisterWrite() decode, or the command<br/>is acked and silently discarded
    C1->>C1: BTS_HandleRegisterWrite() decodes 1012
    C1->>C1: sample both paths at this instant:<br/>ADS pu and internal-ADC volts-at-pin
    C1->>C1: classify by ADS pu: <0.2 low, >0.8 high<br/>else CAL_ERR_PU_RANGE
    C1->>C1: store the point, set eCalStatus bit 1
    C1->>C2: cpu1Status: status bits + telemetry

    C2->>C2: mirror eCalStatus (1020), eCalResult (1024)<br/>and the 9 telemetry registers (1032-1064)
    ESP->>C2: burst read 1008..1064, one transaction
    Note over ESP,C2: skip the lead-in pad byte — the C2000 clocks out<br/>a stale TX byte before its ISR can run
    C2-->>ESP: pad, then 15 big-endian floats
    ESP->>ESP: bts_wire_to_f32() -> bts_cal_state_t
    ESP->>BLE: snapshot updated
    BLE-->>PY: notify e5f1000c at 2 Hz<br/>+ explicit read after the command
    PY->>PY: result == 0 ? continue : raise with result text
    PY-->>OP: "pu = 0.1710 OK / DMM: 0.84968 V"
```

### Two things this diagram is drawn to make obvious

**The endianness flips in the middle.** BLE records are packed
**little-endian** (`ble_proto.h`, native to both the ESP32 and a browser's
`DataView`). The I2C register wire format is **big-endian** (`floatGetWireByte()`
in `com_cpu2.c`). They are opposite, and the conversion happens in `bts_regs.h`
— nothing above `bts_link` should ever see the C2000's byte order.

**CPU1 never writes `registers[]`.** The register file lives in `CPU2TOCPU1RAM`,
which only CPU2 may write. Every measurement CPU1 produces reaches a host by
travelling through `cpu1Status` under its `seq` seqlock and being mirrored by
CPU2. Calibration does not get an exception to this.

---

## 4. Where the numbers come from

The two-point fit, as data rather than as prose. Design doc section 6.

```mermaid
flowchart LR
    subgraph CAP ["Captured per slot"]
        VLO["V low point<br/>(pu_lo, V_lo)"]
        VHI["V high point<br/>(pu_hi, V_hi)"]
        IZ["I zero point<br/>(pu_zero, 0.0 A)"]
        IL["I loaded point<br/>(pu_hi, |I_hi|)"]
    end

    subgraph EXT ["External path — ADS131M08"]
        VGP["VoutGain_pu = (pu_hi - pu_lo) / (V_hi - V_lo)"]
        VOP["VoutOffset_pu = pu_lo - V_lo * VoutGain_pu"]
        VGV["VoutGain_V = 1 / VoutGain_pu"]
        IGP["IoutGain_pu = (pu_hi - pu_zero) / I_hi"]
        IOP["IoutOffset_pu = pu_zero"]
        IGA["IoutGain_A = 1 / IoutGain_pu"]
    end

    subgraph INT ["Internal path — on-chip ADC, x = (sum / (N * 4096)) * 2.5"]
        FVG["F28V_Gain = (V_hi - V_lo) / (x_hi - x_lo)"]
        FVO["F28V_Offset = V_lo - x_lo * F28V_Gain"]
        FIG["F28I_Gain = I_hi / (x_hi - x_zero)"]
        FIO["F28I_Offset = -x_zero * F28I_Gain"]
    end

    VLO --> VGP
    VHI --> VGP
    VGP --> VOP --> VGV
    IZ --> IGP
    IL --> IGP
    IGP --> IOP --> IGA
    VLO --> FVG
    VHI --> FVG
    FVG --> FVO
    IZ --> FIG
    IL --> FIG
    FIG --> FIO

    VGV --> VAL{{"Validate<br/>IoutGain_pu 0.05-0.20<br/>VoutGain_pu 0.10-0.40<br/>F28 gains 0.5-2.0<br/>reciprocals within 0.1%"}}
    IGA --> VAL
    FVO --> VAL
    FIO --> VAL

    VAL -->|pass| FRAM[("FM24V10 F-RAM<br/>128-byte stride<br/>header 0xA5CD_00NN<br/>+ calFlags + crc32")]
    VAL -->|fail| ERR["CAL_ERR_VALIDATE<br/>nothing written"]
    FRAM --> RELOAD["IPC_FLAG2 — CAL_RELOAD<br/>CPU1 re-derives the program"]
    RELOAD --> TICKS["Status bits 13 / 14<br/>green ticks on the display"]
```

Note the **reciprocal pair**. `IoutGain_pu` converts amps to per-unit for the
control loop's setpoint; `IoutGain_A` converts per-unit back to amps for
reporting. They are stored separately and validated against each other to
within 0.1 %, which is what catches a partially-written F-RAM block. The
current *sense* side is never gain-corrected — the loop closes in raw-ADC
per-unit space and calibration is folded into the setpoint only.

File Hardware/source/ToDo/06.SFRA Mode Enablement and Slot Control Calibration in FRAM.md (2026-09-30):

## Mode_[A-C] 0b000 enable SFRA by EN_[A-C] enablement

Each slot can be calibrated for CC and CV control loop with calibration data from the SFRA process. This is currently #define compiled out, but needs to be enabled via the MODE_[A-C] 0b0000 mode-set, with the slot selected for the calibration via the EN_[A-C] slot enablement inputs.

Mode 0b0000 is un-used and shall be use to enable SFRA calibration mode.

In SFRA calibration mode, the AT-Command interface is disabled, and the slot becomes the SFRA serial port for the Ti SFRA calibration tool.

On completion of the SFRA calibration process, the calculated values will be stored in F-RAM, in a section just after the per slot voltage/current calibration, such that it can be done seperately post slot calibration, for slot tuning. The calibration data is calculated externally and must be set via the i2c/api/btle interface register setting process.

Call this feature a slot tuning feature.

We need new registers to store and retrieve slot tuning values, these registers shall go after the unit resigters, at the end of the register mapping as they are not normal run-time registers and only used to store and retrieve slot tuning values during system build, by the system builder. end-users do not perform this slot tuning.

The defaults are below:
#define BTS_DCL_CC_B0                ((float32_t) 0.0331015)
#define BTS_DCL_CC_B1                ((float32_t) -0.0623757)
#define BTS_DCL_CC_B2                ((float32_t)  0.0293372)
#define BTS_DCL_CC_A1                ((float32_t) -1.9605802)
#define BTS_DCL_CC_A2                ((float32_t) 0.9605802)

#define BTS_DCL_CV_KDC               ((float32_t)5000)
#define BTS_DCL_CV_Z0                ((float32_t)0.100)
#define BTS_DCL_CV_Z1                ((float32_t)2.000) // 2
#define BTS_DCL_CV_P1                ((float32_t)2.000) // 2

#define BTS_DCL_CV_B0                ((float32_t) 8.0377472)
#define BTS_DCL_CV_B1                ((float32_t)-13.2244008)
#define BTS_DCL_CV_B2                ((float32_t) 5.2402228)
#define BTS_DCL_CV_A1                ((float32_t)-1.6651931)
#define BTS_DCL_CV_A2                ((float32_t) 0.6651931)

The slot tuning is stored globally on the entire unit, as each slot is the same tuning.

Therefor we have :
DCL_CC_B[0-2]
DCL_CC_A[1-2]
DCL_CV_Z[0-1]
DCL_CV_P[1]
DCL_CV_B[0-2]
DCL_CV_A[1-2]

All float32, defaults above.

On boot, these values are read from f-ram, along with calibration and restart memory, and applied to the CC and CV control loops.

---

## Changelog - PART 1 COMPLETE (slot tuning registers)

**Status: the tuning registers are DONE. The runtime SFRA switch is NOT, and
is filed as ToDo 07.** Split on the user's instruction, because the two halves
are independent and only the registers fit the session.

Compile-verified on both C2000 cores and the ESP32. **No hardware.**

### What landed

**13 tuning registers at 1068-1116**, appended above the unit block:
`DCL_CC_B0..B2/A1/A2`, `DCL_CV_Z0/Z1/P1`, `DCL_CV_B0..B2/A1/A2`.
`TOTAL_REGISTERS` 267 -> 280.

The spec listed these as the defaults to carry. Note they are **not** the
values currently compiled in: `bts_user_settings.h` selects a different CC set
via an `#if/#elif` chain, and a different CV_Z1/P1 pair. The seeding function
takes whatever `BTS_DCL_*` resolve to at build time rather than the literals
in this ToDo, so the defaults match the firmware that ships with them.

**One set for the whole unit**, as specified - every slot is the same
converter. No per-slot stride.

**Z0/Z1/P1 are carried but never read by the firmware.** The DCL runs the
biquad coefficients directly. They record what the coefficients were derived
from so a later re-derivation has the design intent.

**F-RAM record at 0x0700**, 128 B: header `0xA571`, 13 floats, CRC-32. Placed
after the slot-state region that ends at 0x06FF - checked deliberately, since
a previous F-RAM addition collided with the global voltage thresholds.

**Applied at boot and on every host write.** CPU2 restores the record and
raises the existing CAL_RELOAD flag; CPU1 calls `BTS_applySlotTuning()` from
the same handler that reloads calibration. A host write to any coefficient
re-applies the whole block - the biquad is only meaningful as a set, and
writing five coefficients one at a time would otherwise run four passes with a
mixed tuning installed.
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

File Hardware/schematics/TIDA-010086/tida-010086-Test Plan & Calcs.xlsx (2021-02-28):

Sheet: Power Supplies
Supply.Sequence | Supply.Name | Supply.Chipset | Supply.Description | Input.V.Min | Input.V.Nom | Input.V.Max | Input.I.Max | Input.I.Trip | Input.TestPoint+ | Input.TestPoint- | Output.V.Nom | Output.I.Min | Output.I.Nom | Output.I.Max | Output.Vpp | Output.Eff | Output.TestPoint+ | Output.TestPoint-
1 | 12V Protection | LM5060Q1MMX/NOPB |  | 9.00 | 12.00 | 16.80 | 0.50 | 1.00 |  |  | 12.00 | 0.001 |  | 0.50
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

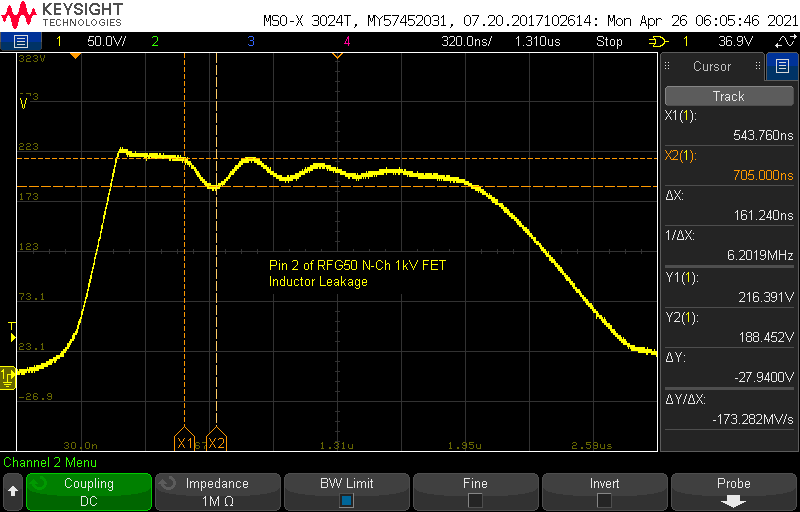
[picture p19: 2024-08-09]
Hardware/mechanical/Test Jig/other/N-Fet pre Snub1.png

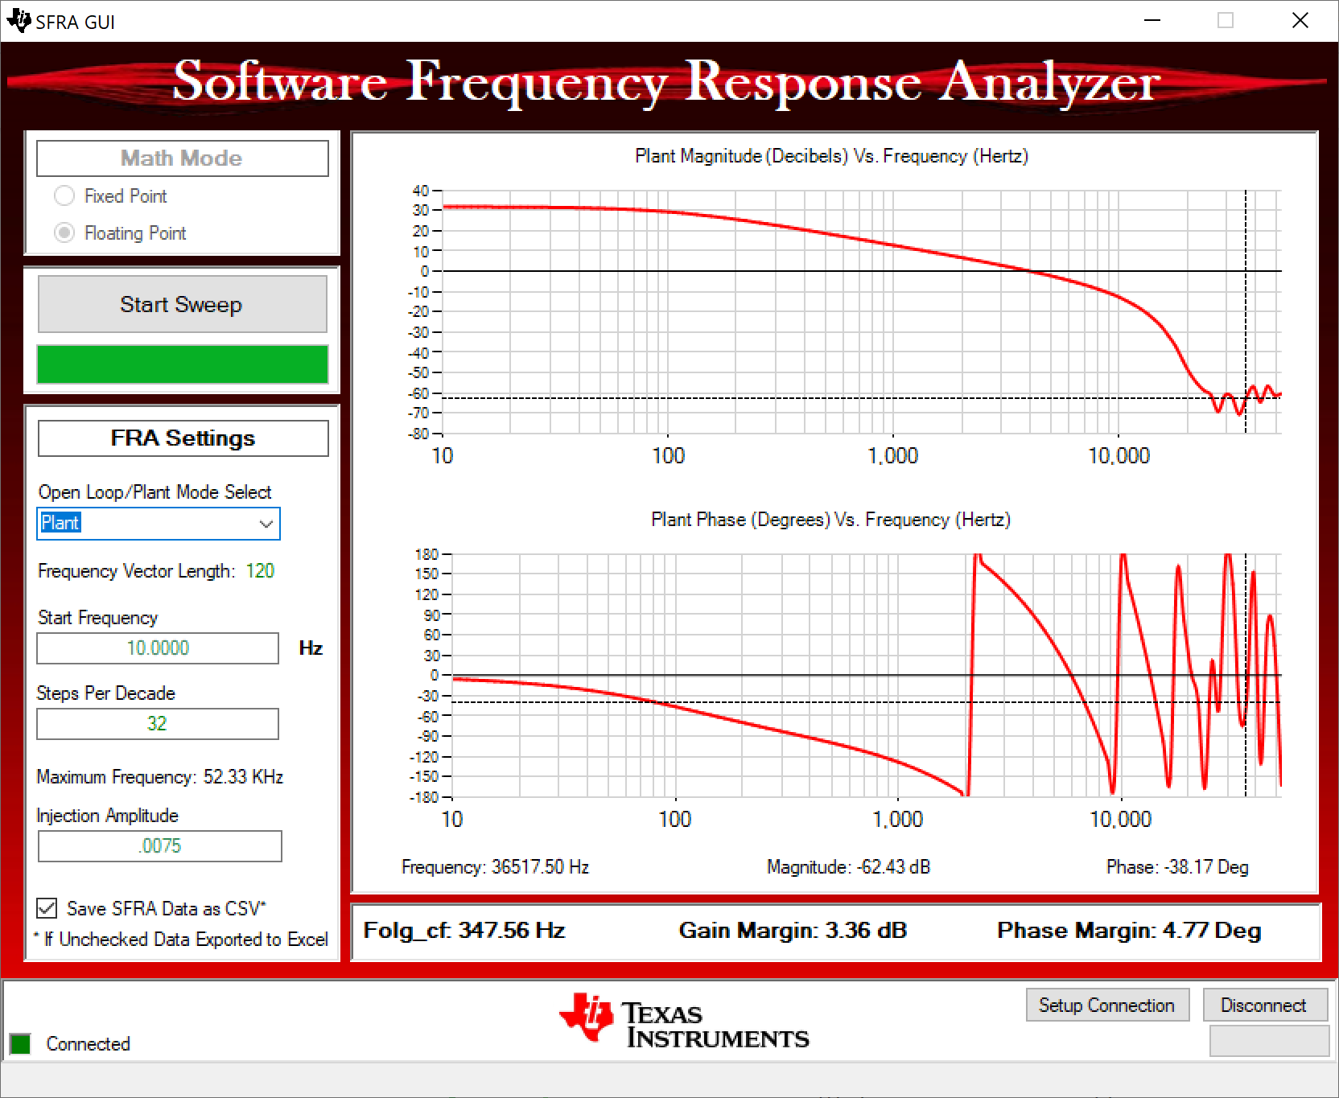
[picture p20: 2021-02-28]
Hardware/schematics/TIDA-010086/Test Data/100khz plant.png

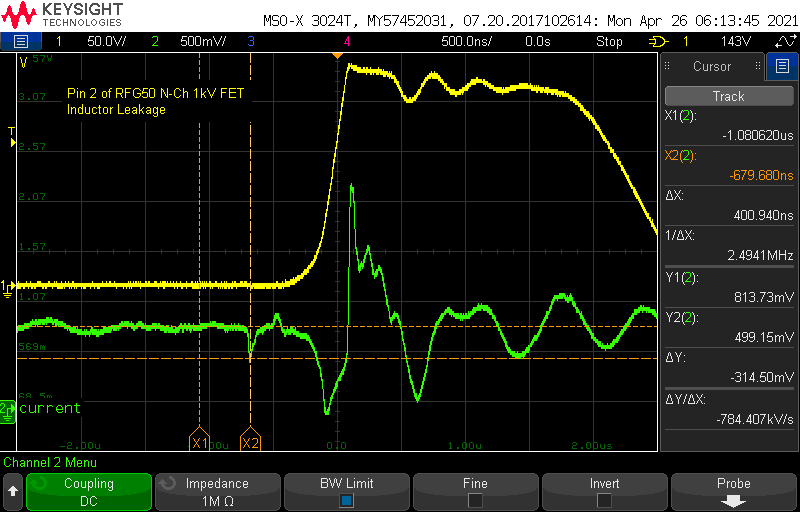
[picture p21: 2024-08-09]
Hardware/mechanical/Test Jig/other/N-Fet pre Snub3.png

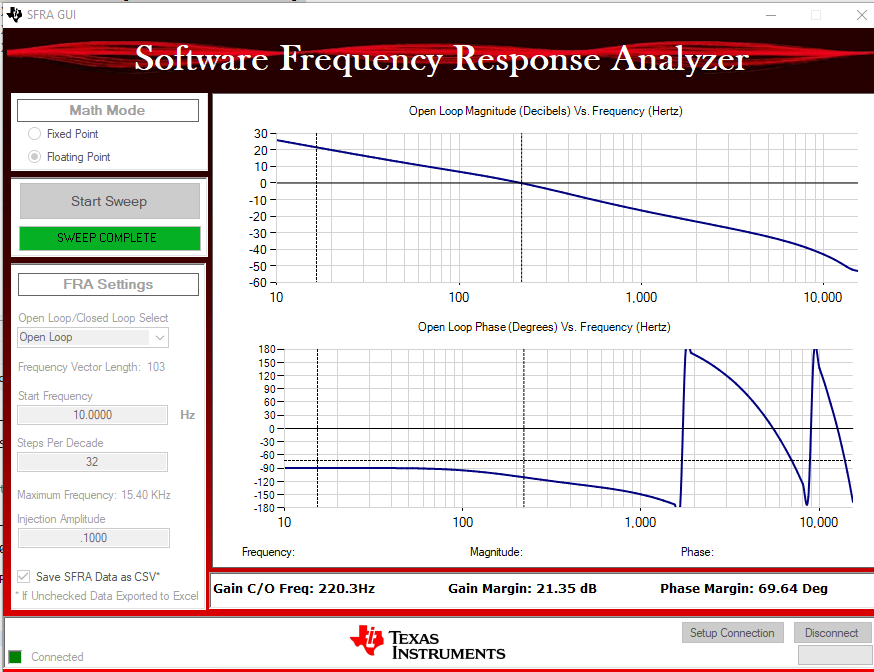
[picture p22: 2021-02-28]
Hardware/schematics/TIDA-010086/Test Data/31.25kHz new DF22 Coeffs - 2 Orig.png

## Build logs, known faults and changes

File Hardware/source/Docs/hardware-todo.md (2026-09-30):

## Hardware todo

AGENT IGNORE THIS FILE. This is for Human's to update the hardware PCB project as a to-do additions.

#### Chnage per slot output connectors to XT60 2+4 PCB mount sockets

Change the NTC and ADS131M08 ADC paths via +4 socket pins

Change the V+- paths via 2 socket pins

#### Update ESP32 block to include rotary encoder and LCD

Add LCD IO to pin-out

Add rotary encoder to pin-out

Remove CC32220SF chip from board

Add additional UART(usb) FT232 output from ESP32 for external AT command access via EP32-i2c bridge.

#### Update laser-cut chassis to include LCD and encoder outputs

Add holes for rotary encoder and LCD view-port.

Include cable harness details for ESP32 to LCD connection

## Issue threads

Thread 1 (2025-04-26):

Tida opamp needs to be Rail to Rail.

ArakniD, 2025-04-26:
Voltage path to f28379d control card min voltage +35mV. Ads131m08 voltage path has +10v/-5v rails so unaffected.

Replace schematic symbol with appropriate opamp like opa192 or opa187 for low offset / drift amp.

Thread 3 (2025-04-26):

Add hysteresis to Reverse Polarity Protection, 100mV offste from gnd

ArakniD, 2025-04-26:

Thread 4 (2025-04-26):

Add ext power rail trip signal to c28, AND in eaxh reverse polariity protection gate drive fot GPIO HRPWM yrip

ArakniD, 2025-04-26:

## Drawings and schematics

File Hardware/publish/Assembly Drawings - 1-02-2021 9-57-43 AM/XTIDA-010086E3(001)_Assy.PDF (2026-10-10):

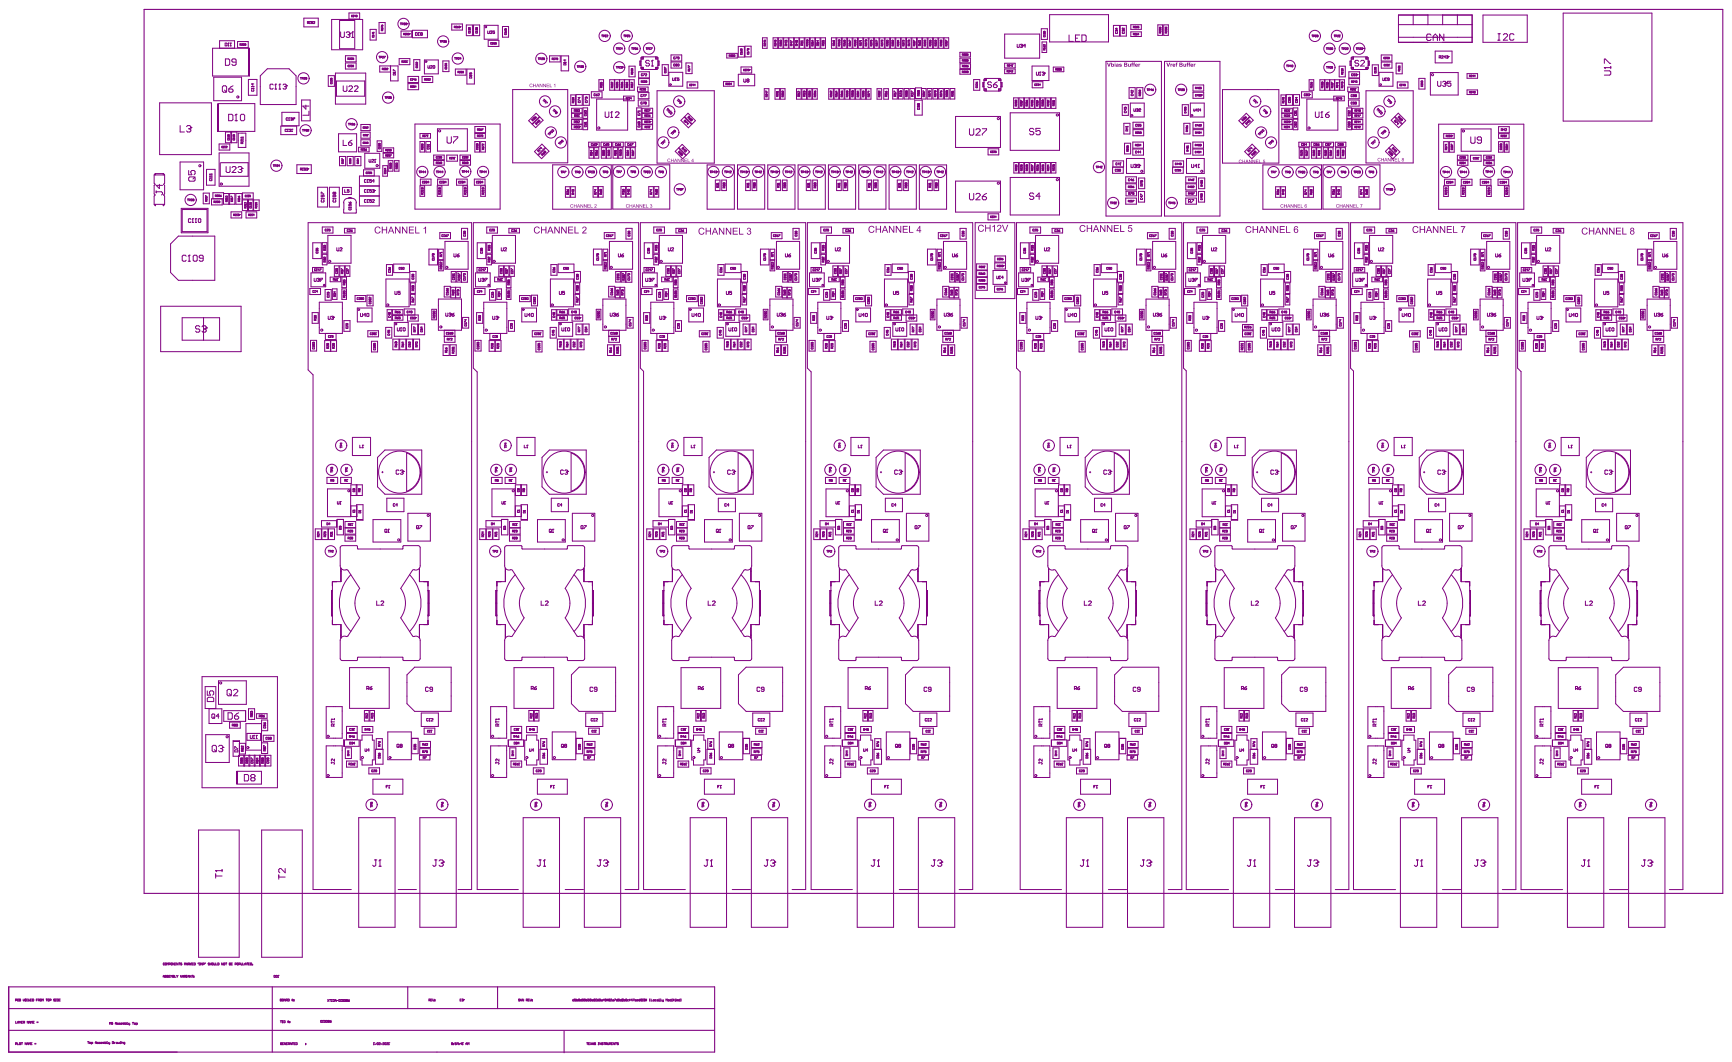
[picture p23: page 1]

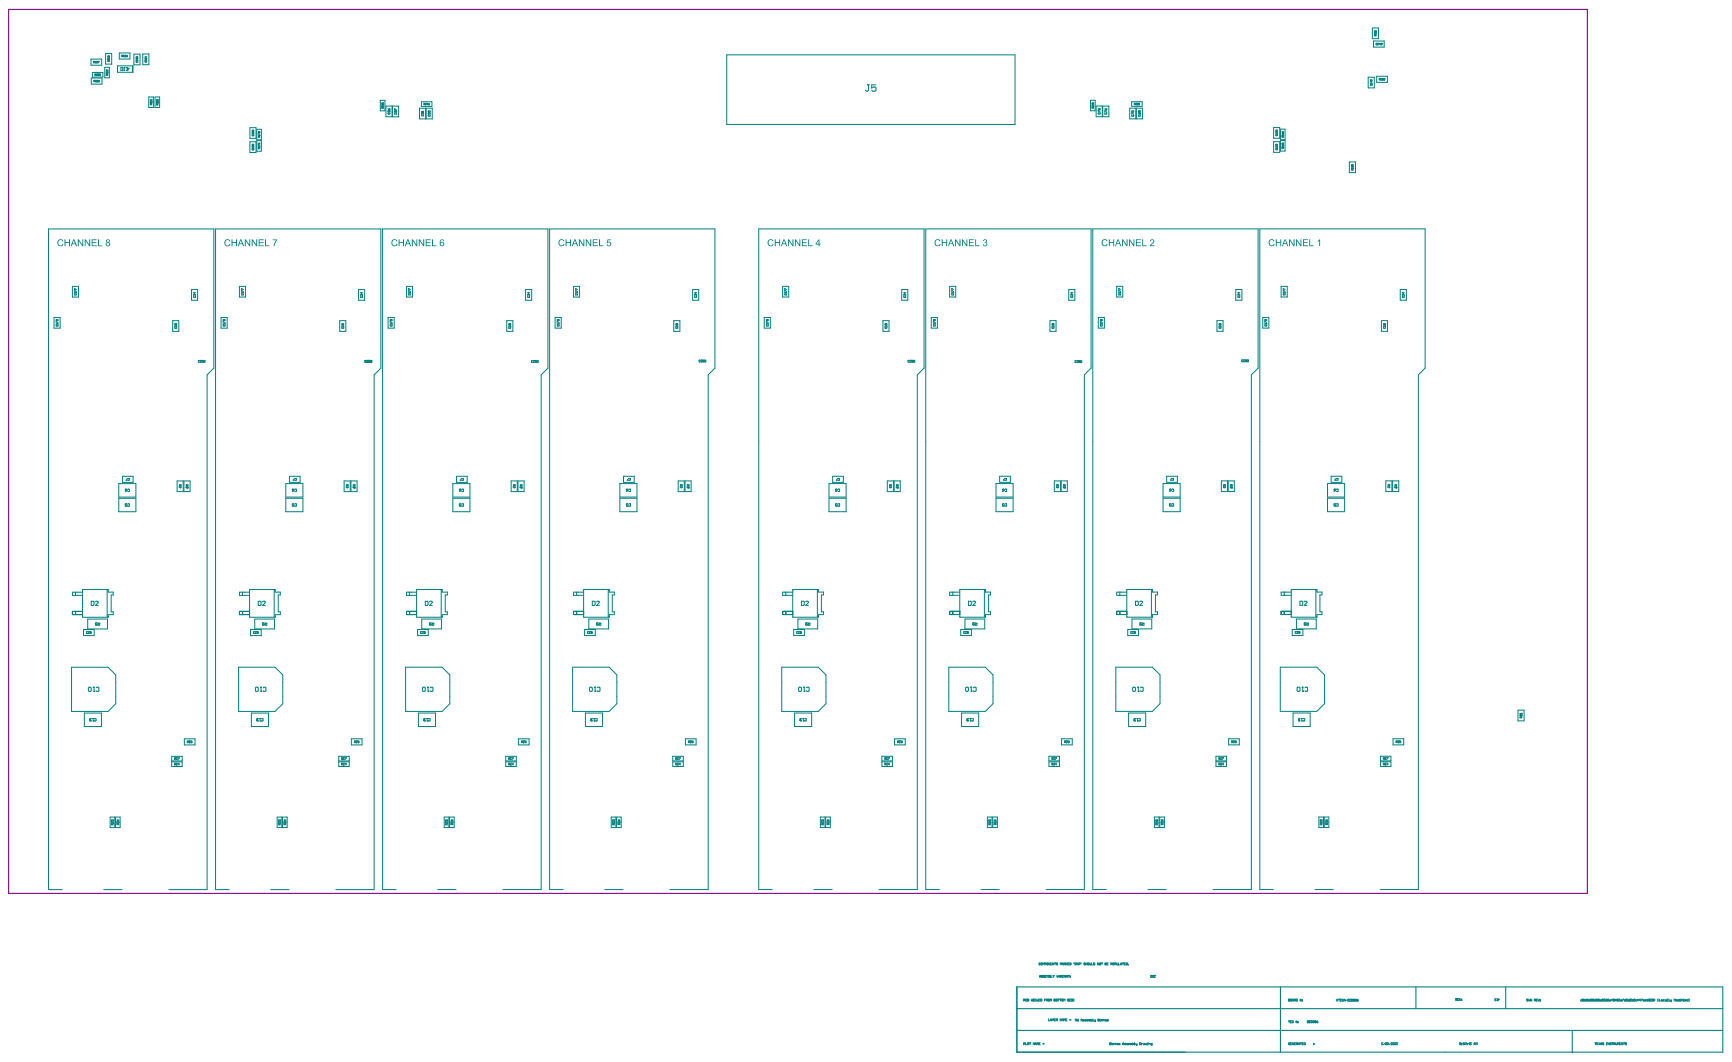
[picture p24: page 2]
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

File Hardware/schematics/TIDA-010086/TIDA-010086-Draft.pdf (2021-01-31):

F

E

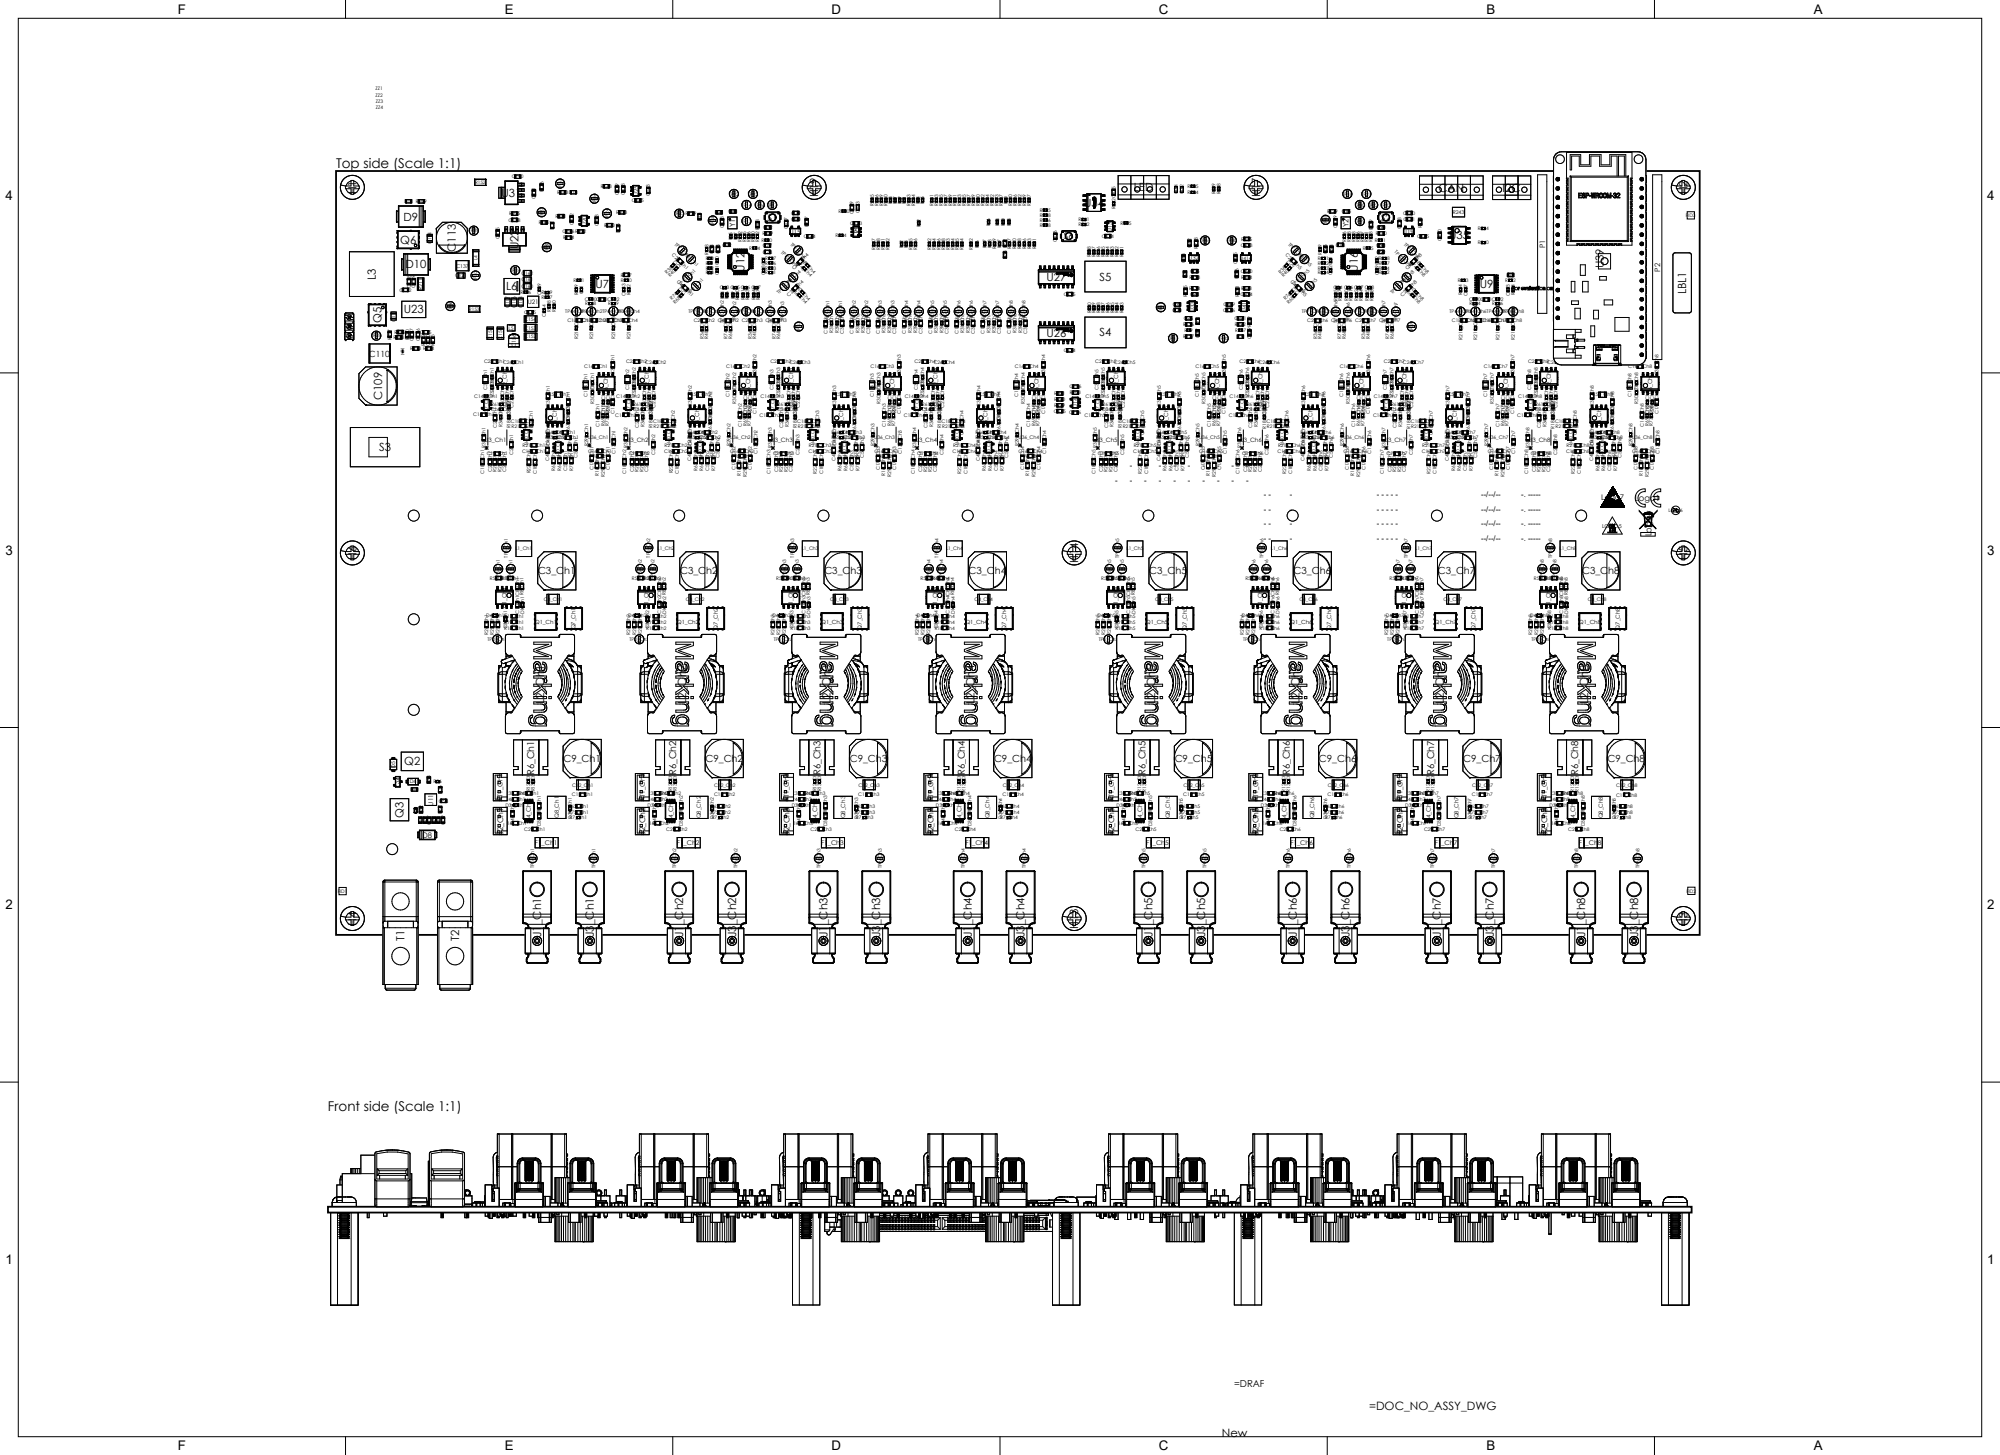
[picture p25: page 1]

F

E

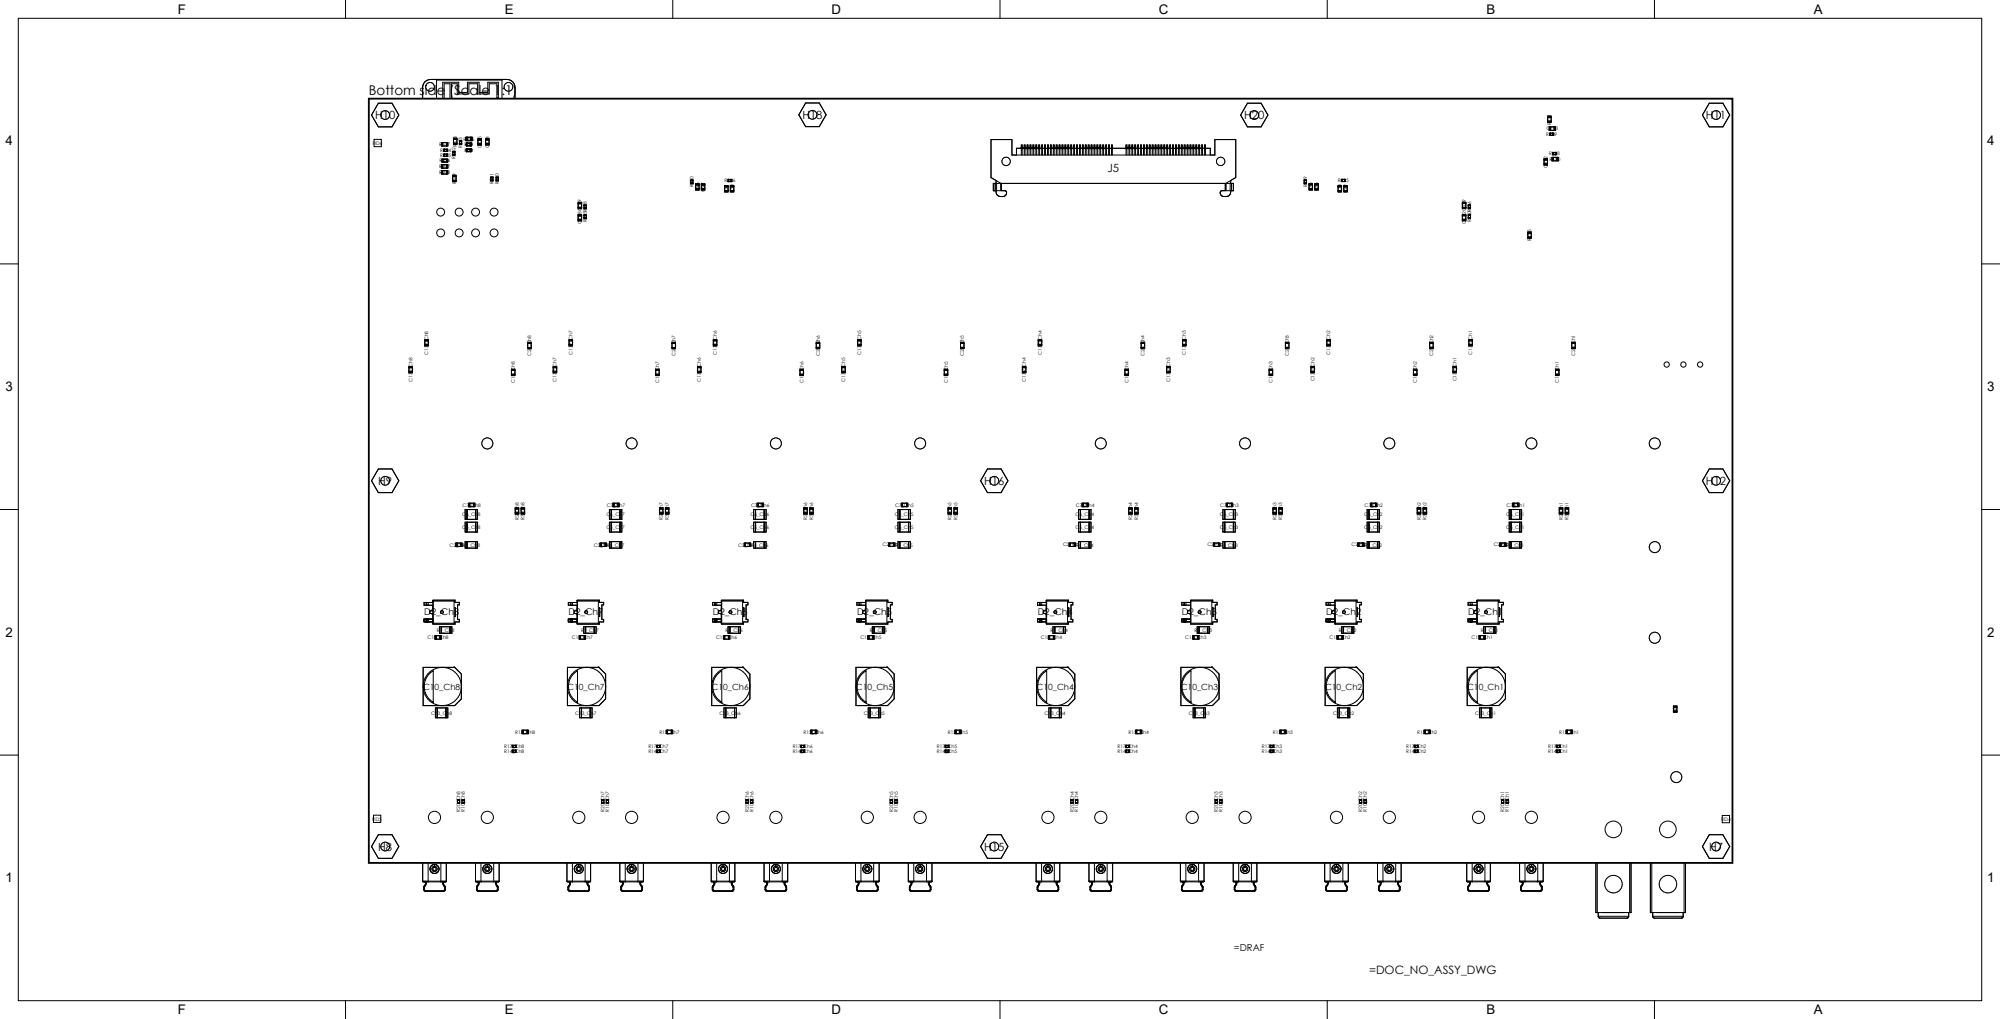
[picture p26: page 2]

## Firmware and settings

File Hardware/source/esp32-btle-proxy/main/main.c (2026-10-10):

/*
 * main.c
 *
 * BTS BLE/WiFi proxy for the TIDA-010086 eight-channel battery tester.
 *
 * HARDWARE
 * --------
 * LOLIN32 v1.0.0 (ESP-WROOM-32) with an on-board lithium charger and a
 * backup cell, wired to the BTS unit's I2C communication port. The backup
 * cell is what makes the boot-time stop in test_engine_init() necessary:
 * the proxy can outlive a BTS power cycle, so at startup it has no idea
 * what the unit is doing and must not assume the channels are idle.
 *
 * I2C
 * ---
 * GPIO21/22 are the LOLIN32's default SDA/SCL pins and are free on this
 * board. The BTS is the only target on the bus, at 0x50.
 *
 * INIT ORDER
 * ----------
 * NVS first, because both cell_profiles and result_store read from it.
 * bts_link before test_engine, because the engine stops every channel as
 * its first act. ble_svc and web_api last: both call into the engine.
 */

#include <stdio.h>
#include "at_console.h"
#include "freertos/FreeRTOS.h"
#include "freertos/task.h"
#include "esp_log.h"
#include "esp_system.h"
#include "esp_chip_info.h"
#include "nvs_flash.h"

#include "bts_link.h"
#include "cell_profiles.h"
#include "test_engine.h"
#include "result_store.h"
#include "ble_svc.h"
#include "web_api.h"
#include "display.h"
#include "input.h"
#include "led_strip.h"
#include "ota.h"

static const char *TAG = "main";

/* LOLIN32 default I2C pins. */
#define BTS_SDA_GPIO        21
#define BTS_SCL_GPIO        22
#define BTS_I2C_HZ          100000
#define BTS_POLL_MS         250

/*
 * ST7789 status display on SPI2 (HSPI), using the hardware MOSI/SCK pads so
 * the SPI peripheral drives them through the IO_MUX rather than the GPIO
 * matrix. None of these collide with the BTS I2C pins or the console UART.
 *
 * CS is a real GPIO: this module has no tie to ground. GPIO19 has no strapping
 * role, and an external 10k pull-up to 3V3 holds the panel deselected from
 * reset until the driver takes the pin.
 */
#define LCD_MOSI_GPIO       23
#define LCD_SCLK_GPIO       18
#define LCD_CS_GPIO         19
#define LCD_RESET_GPIO      17
#define LCD_DC_GPIO         16
#define LCD_BACKLIGHT_GPIO  4

/*
 * Rotary encoder with push switch, and the extra KEY0 button. None of these
 * is a strapping or JTAG pin; see input.h.
 *
 * A and the switch were on GPIO15 and GPIO2, both strapping pins, and moved
 * to GPIO32 and GPIO33. B moved off GPIO13 earlier, when the WS2812B driver
 * took that pin for SPI3 MOSI. GPIO14 was not used for B: it is MTMS, and a
 * JTAG pin on the encoder would make the box awkward to debug over JTAG later.
 *
 * KEY0 is on GPIO34, which is input only with no internal pull. The LCD board
 * pulls KEY0 up to 3V3, so it needs none.
 */
#define ENC_A_GPIO          32
#define ENC_B_GPIO          27
#define ENC_SW_GPIO         33
#define KEY0_GPIO           34

/*
 * WS2812B slot indicators, one per slot, on SPI3 (VSPI) MOSI.
 *
 * SPI3 and not SPI2: the ST7789 above holds SPI2 (HSPI), despite sitting on
 * the GPIO23/18 pads that are VSPI's IO_MUX defaults - it reaches them
 * through the GPIO matrix. Sharing one host would let an LED frame stall a
 * panel repaint and vice versa.
 *
 * See led_strip.h for the bitstream encoding and for why this is on the
 * ESP32 at all rather than on the C2000 that owns the slots.
 */
#define LED_DATA_GPIO       13

#define BLE_DEVICE_NAME     "BTS-Tester"
#define AP_SSID             "BTS-Tester"
/*
 * Open AP. The bench network is the security boundary; a WPA2 key baked
 * into firmware that ships on a tester is not one. Set station credentials
 * with POST /api/wifi to get it onto a real network.
 */
#define AP_PASSWORD         NULL

static void log_boot_banner(void)
{
    esp_chip_info_t chip;
    esp_chip_info(&chip);

    ESP_LOGI(TAG, "BTS proxy starting: %s rev %u, %d core(s), heap %u",
             CONFIG_IDF_TARGET, (unsigned)chip.revision, chip.cores,
             (unsigned)esp_get_free_heap_size());

    if (esp_reset_reason() == ESP_RST_BROWNOUT) {
        /*
         * Worth calling out: on a unit with a backup cell a brownout means
         * the cell is flat or the charger is not keeping up, and every test
         * that was running has been lost.
         */
        ESP_LOGW(TAG, "last reset was a brownout - check the backup battery");
    }
}

void app_main(void)
{
    log_boot_banner();

    esp_err_t err = nvs_flash_init();
    if (err == ESP_ERR_NVS_NO_FREE_PAGES || err == ESP_ERR_NVS_NEW_VERSION_FOUND) {
        ESP_LOGW(TAG, "default NVS needs erase, reformatting");
        ESP_ERROR_CHECK(nvs_flash_erase());
        err = nvs_flash_init();
    }
    ESP_ERROR_CHECK(err);

    /*
     * The I2C driver logs an error per failed transfer. With the BTS absent
     * that is four lines every 250 ms, which buries everything else on the
     * console. bts_link already reports link state at a sane rate, so the
     * driver's own chatter is turned down to ERROR-and-above off.
     */
    esp_log_level_set("i2c.master", ESP_LOG_NONE);
    esp_log_level_set("i2c.common", ESP_LOG_NONE);

    ESP_ERROR_CHECK(cell_profiles_init());
    ESP_ERROR_CHECK(result_store_init());

    const bts_link_config_t bts_cfg = {
        .sda_gpio         = BTS_SDA_GPIO,
        .scl_gpio         = BTS_SCL_GPIO,
        .scl_speed_hz     = BTS_I2C_HZ,
        .poll_interval_ms = BTS_POLL_MS,
    };
    ESP_ERROR_CHECK(bts_link_init(&bts_cfg));

    /*
     * Straight after the link, and before anything that could fail: if this
     * image arrived over the air it is on trial, and ota_init() starts the
     * task that confirms it once the BTS answers. On an image that is not on
     * trial - every USB-flashed one - this returns immediately.
     */
    err = ota_init();
    if (err != ESP_OK) {
        /*
         * Not fatal, but it does mean an OTA-delivered image will roll back
         * on its next reboot, so it is logged loudly rather than ignored.
         */
        ESP_LOGE(TAG, "OTA confirm task did not start: %s - an updated image "
                      "will roll back", esp_err_to_name(err));
    }

    ESP_ERROR_CHECK(test_engine_init());

    /*
     * The display comes up before BLE and WiFi so that a boot failure in
     * either is visible on the panel rather than only on the console. It is
     * a pure consumer of test_engine and bts_link state, so it needs those
     * two initialised first but nothing after it.
     */
    const display_config_t lcd_cfg = {
        .mosi_gpio      = LCD_MOSI_GPIO,
        .sclk_gpio      = LCD_SCLK_GPIO,
        .cs_gpio        = LCD_CS_GPIO,
        .reset_gpio     = LCD_RESET_GPIO,
        .dc_gpio        = LCD_DC_GPIO,
        .backlight_gpio = LCD_BACKLIGHT_GPIO,
        .width          = 240,
        .height         = 240,
        .x_offset       = 0,
        .y_offset       = 0,
        .invert_colour  = true,
        /*
         * Mode 2 and a slow clock while the panel is being brought up.
         * Mode 0 is the ST7789 datasheet default, but several breakout
         * boards latch on the opposite edge; the bus is write-only so a
         * mismatch is silent. Once the self-test pattern is confirmed,
         * raise pclk_hz and, if it still works, try mode 0.
         */
        .spi_mode       = 2,
        .pclk_hz        = 10 * 1000 * 1000,
        .self_test      = true,
        .refresh_ms     = 500,
    };
    err = display_init(&lcd_cfg);
    if (err != ESP_OK) {
        /* A tester with no panel is still a working tester over BLE. */
        ESP_LOGE(TAG, "display unavailable: %s", esp_err_to_name(err));
    }

    const input_config_t enc_cfg = {
        .encoder_a_gpio    = ENC_A_GPIO,
        .encoder_b_gpio    = ENC_B_GPIO,
        .switch_gpio       = ENC_SW_GPIO,
        .switch_active_low = true,      /* switch to GND, internal pull-up */
        .key0_gpio         = KEY0_GPIO, /* to GND, board pull-up to 3V3    */
        .long_press_ms     = 800,
        .invert_direction  = false,
        .trace             = true,
    };
    err = input_init(&enc_cfg);
    if (err != ESP_OK) {
        ESP_LOGE(TAG, "encoder unavailable: %s", esp_err_to_name(err));
    }

    const led_strip_config_t led_cfg = {
        .data_gpio  = LED_DATA_GPIO,
        /*
         * 25 ms: fast enough that the 125 ms half-period of the quickest
         * flash (reverse polarity) still gets five frames, and slow enough
         * that the strip costs well under a percent of one core.
         */
        .refresh_ms = 25,
        /*
         * These sit in an operator's eyeline on a bench. Full brightness on
         * eight WS2812Bs is both hard to look at and 480 mA if every pixel
         * ever went white at once.
         */
        .brightness = 64,
    };
    err = led_strip_init(&led_cfg);
    if (err != ESP_OK) {
        /* Dark indicators; BLE, HTTP and the AT console are unaffected. */
        ESP_LOGE(TAG, "LED strip unavailable: %s", esp_err_to_name(err));
    }

    ESP_ERROR_CHECK(ble_svc_init(BLE_DEVICE_NAME));

    const web_api_config_t web_cfg = {
        .ap_ssid     = AP_SSID,
        .ap_password = AP_PASSWORD,
        .port        = 80,
    };
    /*
     * Not fatal. BLE is the primary operator interface, so a tester with no
     * network is still a usable tester - do not take the whole box down
     * because WiFi did not come up.
     */
    err = web_api_init(&web_cfg);
    if (err != ESP_OK) {
        ESP_LOGE(TAG, "web API unavailable: %s (BLE still up)", esp_err_to_name(err));
    }

    ESP_LOGI(TAG, "ready, free heap %u", (unsigned)esp_get_free_heap_size());

    /*
     * The AT console goes LAST, and the ordering is load bearing: starting it
     * silences ESP_LOG on UART0, so everything above still reports its own
     * failures to a console that is watching. Bring it up first and a WiFi or
     * BLE error would vanish.
     *
     * It takes the port because it has to. An AT dialogue and a log stream
     * cannot share a UART - log lines would interleave with responses and
     * break any parser expecting a clean "+NAME=value\r\nOK\r\n". Losing
     * the serial log was accepted deliberately; logs are still reachable over
     * the network interfaces.
     *
     * Not fatal, for the same reason the web API is not: a tester with no AT
     * console is still a usable tester over BLE and HTTP.
     */
    err = at_console_start();
    if (err != ESP_OK) {
        ESP_LOGE(TAG, "AT console unavailable: %s", esp_err_to_name(err));
    }
}

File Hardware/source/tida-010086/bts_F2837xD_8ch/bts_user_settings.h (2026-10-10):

/*
 * bts_settings.h
 *
 *  Created on: Aug 11, 2020
 *      Author: a0230328
 */
//custom settings

#ifndef BTS_USER_SETTINGS_H_
#define BTS_USER_SETTINGS_H_

#include "bts_user_calibration.h"

//
//=============================================================================
// Build mode: GPIO28/29 role selection
//=============================================================================
//
// GPIO28 and GPIO29 are physically shared between three functions, so the
// build has to choose. BTS_DEBUG_CONSOLE selects which:
//
//   BTS_DEBUG_CONSOLE == true   (bench debug)
//     GPIO28 = SCIRXDA, GPIO29 = SCITXDA. The AT command console runs on
//     SCIA, reachable over the TMDSCNCD28379D's isolated FTDI backchannel -
//     the COM port that enumerates on the same USB cable as the XDS100v2.
//     Channel 1's GPIO trip input shares GPIO28 and is therefore disabled;
//     it is not physically connected in this configuration. The WS2812B
//     LED string is disabled too, as it needs GPIO29.
//
//   BTS_DEBUG_CONSOLE == false  (production)
//     GPIO28 = channel 1 GPIO trip input (digital in).
//     GPIO29 = SCITXDA, idle. The AT command console is not available in
//     this build - there is no free SCI port for it, so the host uses I2C
//     or CAN.
//
// SCIB is not an alternative: GPIO18 is SPICLKA and GPIO19 is the ADC1 chip
// select for the external 24-bit SPI ADCs.
//
// Channel 1 keeps its CMPSS over-current trip in both modes. Only the
// separate GPIO trip input is affected.
//
// PRODUCTION since 2026-10-02. The AT console moved to the ESP32, which
// serves the same grammar over I2C (see Docs/at-command-specification.md).
//
// THE LED STRING ALSO MOVED TO THE ESP32, 2026-10-02, and the SCIA driver
// that used to feed it is permanently off - see BTS_LED_DRIVER_ENABLED.
//
#define BTS_DEBUG_CONSOLE (false)

//
// BTS_LED_DRIVER_ENABLED IS FALSE IN BOTH ARMS AND SHOULD STAY THAT WAY.
//
// The WS2812B string is driven by the ESP32 now, over SPI3 on its GPIO13.
// The C2000 driver that used to do it could never have worked: it clocked
// raw colour bytes out of SCIA at 800 kbaud, but a WS2812B decodes pulse
// WIDTHS - 400 ns high is a 0, 800 ns high is a 1 - and a UART cannot
// produce them. It forces a LOW start bit before every byte and holds each
// data bit for a full 1250 ns bit time, so the strip saw framing noise and
// latched nothing. No pixel ever lit from this core.
//
// Driving it properly needs a peripheral that can emit a free-running bit
// pattern, which here means SPI. GPIO29 - the wire that is physically
// present - has no SPI mux option (GPIO, SCITXDA, EM1SDCKE, OUTPUTXBAR6,
// EQEP3B, SD2_C3), and both usable SPI ports are held by the ADS131M08
// pair. Hence the move. See esp32-btle-proxy/components/led_strip/.
//
// Setting this true again re-enables dead code AND hands SCIA to it, so do
// not do it to get the console back - use BTS_DEBUG_CONSOLE for that.
//
#if (BTS_DEBUG_CONSOLE == true)
    //
    // Bench debug: SCIA carries the AT console on the FTDI backchannel.
    //
    #define BTS_CONSOLE_ENABLED       (true)
    #define BTS_CONSOLE_SCI_BASE      SCIA_BASE
    #define BTS_CONSOLE_TX_PINCONFIG  GPIO_29_SCITXDA
    #define BTS_CONSOLE_RX_PINCONFIG  GPIO_28_SCIRXDA
    #define BTS_CONSOLE_RX_INT        INT_SCIA_RX
    // The FTDI backchannel is a standard 115200 8N1 port.
    #define BTS_CONSOLE_BAUDRATE      ((uint32_t)115200)

    // GPIO29 is the console TX, so the LED string cannot have it.
    #define BTS_LED_DRIVER_ENABLED    (false)
#else
    //
    // Production: no console. GPIO29 is left muxed to SCITXDA and idle -
    // the LED string it used to feed is driven by the ESP32 now.
    //
    #define BTS_CONSOLE_ENABLED       (false)
    #define BTS_LED_DRIVER_ENABLED    (false)
#endif

#define BTS_ENABLE_DETECT_CODE (false)
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

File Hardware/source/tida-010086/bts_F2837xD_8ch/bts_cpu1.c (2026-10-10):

/*
 * bts_cpu1.c (previously bts_main.c)
 *
 * TITLE: Main file for the solution
 *        Additional solution support files are
 *            <solution>.c -> solution source file
 *            <solution>.h -> solution header file
 *            <solution>_settings.h -> powerSUITE generated settings
 *            <solution>_hal.c -> device drivers source file
 *            <solution>_hal.h -> device drivers header file
 *
 * Copyright (C) 2020 Texas Instruments Incorporated - http://www.ti.com/
 * ALL RIGHTS RESERVED
 */

#ifdef CPU1
#include <bts.h>
#include "registers.h"
#include "bts_cla_shared.h"
#include <math.h>

//
//--- State Machine Related ---
//
uint16_t vTimer0[4];         // Virtual Timers based on CPU Timer 0 (A events)
uint16_t vTimer1[4];         // Virtual Timers based on CPU Timer 1 (B events)
uint16_t vTimer2[4];         // Virtual Timers based on CPU Timer 2 (C events)

//
// Variable declarations for state machine
//
void (*Alpha_State_Ptr)(void); // Base States pointer
void (*A_Task_Ptr)(void);      // State pointer A branch
void (*B_Task_Ptr)(void);      // State pointer B branch
void (*C_Task_Ptr)(void);      // State pointer C branch


__interrupt void adcCellVoltageISR(void);

//
// Local helpers
//
static void updateInputVoltage(void);
static void checkGroupIntegrity(void);
static void publishStatusToCpu2(void);
static void serviceTermination(void);
static void servicePreChargeBalance(void);
static void serviceDivergenceFault(void);

//
// Consecutive C1 passes each slot has satisfied its termination condition.
//
// A charge ends on a CURRENT threshold, and current is the noisiest thing
// measured here - a single sample dipping under I_MIN is not a finished
// charge. The condition has to hold for BTS_TERM_DWELL_PASSES passes in a
// row; anything failing resets the count to zero.
//
// Reset by slotStop(), slotFinish() and a fresh start, so a resumed slot
// earns its termination again from scratch rather than inheriting progress
// from before it was held.
//
static uint16_t termDwell[NUM_CHANNELS];

//
// Pre-charge balance supervisor state. All indexed by slot.
//
//   balanceDwell      consecutive passes the current condition has held, and
//                     doubles as the BALANCING / SOFT_START elapsed counter
//   softStartRetries  attempts used, against BTS_SOFT_START_MAX_RETRIES
//   softStartHold     passes still to wait out after a trip, ~100 ms
//
static uint16_t balanceDwell[NUM_CHANNELS];
static uint16_t softStartRetries[NUM_CHANNELS];
static uint16_t softStartHold[NUM_CHANNELS];
static uint16_t divergeDwell[NUM_CHANNELS];
static uint16_t softStartElapsed[NUM_CHANNELS];

//
// How long a termination condition must hold. C1 is nominally 10 Hz but was
// measured on hardware at 0.69 Hz, so this is deliberately expressed in
// PASSES rather than seconds - at the nominal rate it is ~0.5 s and at the
// measured rate ~7 s. Both are short against any real charge and long
// against measurement noise.
//
#define BTS_TERM_DWELL_PASSES  ((uint16_t)5)

//
// CLA1 - the internal-ADC telemetry filter. See bts_cla.cla.
//
static void BTS_initCla(void);
static void BTS_updateFilteredTelemetry(void);
static void BTS_refreshCellFromCla(void);

//
// 1 while CLA1 is not demonstrably advancing BTS_claRunCount. Set by
// BTS_updateFilteredTelemetry() and read by BTS_refreshCellFromCla(), which
// leaves the cell readings alone rather than fabricating a 0 V when it is
// set. Non-static so it can be watched from the debugger during bring-up.
//
volatile uint16_t claFastStale = 1U;
void updateStatusRegisters(void);
void modeCallback(float value, uint16_t channel);
void BTS_HandleRegisterWrite(void);

//
// Runtime slot calibration (design doc sections 5-7). CPU1 owns the state
// machine and the captures; CPU2 owns registers[] and the F-RAM write.
//
static void calHandleCommand(uint16_t opcode, float32_t argument);
static void calServiceDeadMan(void);
static void calPublishTelemetry(void);
static uint16_t calSlotIsCalibrating(uint16_t ch);

//
// State Machine function prototypes
//------------------------------------
// Alpha states
//
void A0(void);  //state A0
void B0(void);  //state B0
void C0(void);  //state C0

//
// A branch states
//
void A1(void);  //state A1
void A2(void);  //state A2
void A3(void);  //state A3

//
// B branch states
//
void B1(void);  //state B1
void B2(void);  //state B2
void B3(void);  //state B3

//
// C branch states
//
void C1(void);  //state C1
void C2(void);  //state C2
void C3(void);  //state C3

#ifdef _STANDALONE
//
// Bounded CPU2 boot - see tryBootCpu2(). Declared here because main() and
// C3() both call it and it is defined further down.
//
// Per-attempt ceiling on waiting for CPU2's ROM. CPU2 reaches SYSTEM_READY
// within microseconds of reset; by the time CPU1 gets here it has spent many
// milliseconds in its own init, so a healthy CPU2 is already waiting and
// this only ever bounds the failure case.
//
#define BTS_CPU2_BOOT_TIMEOUT_US    500000UL
#define BTS_CPU2_BOOT_POLL_US          100UL

#ifdef _FLASH
#define BTS_CPU2_BOOT_MODE   C1C2_BROM_BOOTMODE_BOOT_FROM_FLASH
#else
#define BTS_CPU2_BOOT_MODE   C1C2_BROM_BOOTMODE_BOOT_FROM_RAM
#endif

static bool tryBootCpu2(uint32_t timeoutUs);
#endif

// Global unit state
volatile UnitState unitState = eInputOK;

//
// Bound on the ADCB end-of-conversion poll in updateInputVoltage(). The
// conversion itself is sub-microsecond; this only has to be large enough
// not to false-trip, and finite so a dead flag cannot wedge the task loop.
//
#define BTS_ADCB_EOC_MAX_POLLS ((uint16_t)2000)

//
// Diagnostic counter: non-zero means the input-voltage read timed out and
// the guard is running on a substituted 0 V rather than a live measurement.
//
volatile uint32_t adcbEocTimeouts = 0;

//
//=============================================================================
// Charge / energy accumulators
//=============================================================================
//
// Integrated from the ADS131M08 pair - the same sensor the CC loop regulates
// against - rather than the 12-bit internal ADC in the stats block.
//
// Charge and discharge accumulate their own positive magnitudes, so a charge
// followed by a discharge on one slot leaves two separate totals instead of
// cancelling. Each pair is zeroed only when its own direction starts.
//
static float32_t accChargeMah[NUM_CHANNELS];
static float32_t accChargeMwh[NUM_CHANNELS];
static float32_t accChargeSeconds[NUM_CHANNELS];
static float32_t accDischargeMah[NUM_CHANNELS];
static float32_t accDischargeMwh[NUM_CHANNELS];
static float32_t accDischargeSeconds[NUM_CHANNELS];

//
// Tick at which each slot last accumulated. 0 means "no baseline" - the next
// pass establishes one and integrates nothing, so a slot can never bank the
// whole interval since boot on its first sample.
//
static uint32_t accLastTick[NUM_CHANNELS];
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

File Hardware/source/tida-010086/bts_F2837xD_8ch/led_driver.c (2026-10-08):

/*
 * led_driver.c
 *
 *  Created on: 15 Apr. 2025
 *      Author: lucas
 */


#include "led_driver.h"
#include "device.h"

#ifdef CPU2
#if (BTS_LED_DRIVER_ENABLED == true)

// LED colour tables (GRB order for WS2812B)
static const uint16_t colorRed[3]   = COLOR_RED;
static const uint16_t colorGreen[3] = COLOR_GREEN;
static const uint16_t colorBlue[3]  = COLOR_BLUE;
static const uint16_t colorWhite[3] = COLOR_WHITE;
static const uint16_t colorYellow[3] = COLOR_YELLOW;

// LED buffer (GRB order)
static uint16_t ledBuffer[LED_BUFFER_SIZE];

//
// Set by the timer ISR, cleared by LEDDriver_due().
//
// THE TRANSFER USED TO HAPPEN IN THE ISR AND THAT WAS THE BUG. Clocking 24
// bytes at 800 kbaud takes 300 us, and the WS2812B reset pulse adds another
// 60 us of busy-wait. ledTimerISR is not declared HPI - unlike every other
// ISR on this core - so it ran with interrupts disabled for the whole ~360 us,
// 80 times a second.
//
// What that broke: CPU2's I2C target ISR fires on EVERY received byte
// (SCI_FIFO_RX1) and was measured at 3-8 kHz while the ESP32 polls. A byte
// arrives every 130-300 us, so each LED refresh masked one or two of them.
// The ESP32 saw failed reads, its display cycled between "WAITING FOR BTS"
// and live data, and CPU2's own 8 Hz heartbeat stretched to roughly a minute.
//
// Confirmed on hardware 2026-10-02 by stopping Timer 2 with the debugger:
// the ESP32 link went solid immediately.
//
static volatile bool ledRefreshDue = false;

// UART initialization for WS2812B
void LEDDriver_init(void) {
    //
    // GPIO29 is muxed to SCITXDA by CPU1 in BTS_HAL_setupCpu2Pins(); the mux
    // registers are not writable from CPU2.
    //

    // UART config: 800 kbps (WS2812B timing), 8-bit, no parity
    SCI_setConfig(SCIA_BASE, DEVICE_LSPCLK_FREQ, 800000, (SCI_CONFIG_WLEN_8 | SCI_CONFIG_STOP_ONE | SCI_CONFIG_PAR_NONE));
    SCI_resetChannels(SCIA_BASE);
    SCI_enableFIFO(SCIA_BASE);
    SCI_enableModule(SCIA_BASE);
    SCI_performSoftwareReset(SCIA_BASE);
    SCI_disableInterrupt(SCIA_BASE, SCI_INT_RXRDY_BRKDT | SCI_INT_TXRDY);

    //
    // Timer for LED updates, 80 Hz for smooth flashing.
    //
    // CPU TIMER 2, NOT TIMER 0. Timer 0 is the ADS1119 dwell timebase, and
    // initADS1119() reprograms it to a free-running 0xFFFFFFFF period with
    // the interrupt DISABLED. main() calls initADS1119() after this function,
    // so on Timer 0 the LED tick was silently switched off moments after it
    // was started - the string never updated in a production build.
    //
    // Timer 2 is free ON CPU2 ONLY. It is not free on CPU1: the task
    // scheduler owns it as TASKC_CPUTIMER_BASE, and BTS_HAL_measureSysclkKHz()
    // borrows it to count INTOSC1. CPU2 runs neither.
    //
    CPUTimer_setPeriod(CPUTIMER2_BASE, DEVICE_SYSCLK_FREQ / 80);
    CPUTimer_setPreScaler(CPUTIMER2_BASE, 0);
    CPUTimer_enableInterrupt(CPUTIMER2_BASE);
    Interrupt_register(INT_TIMER2, &ledTimerISR);
    Interrupt_enable(INT_TIMER2);
    CPUTimer_startTimer(CPUTIMER2_BASE);

    // Clear LED buffer
    for (uint16_t i = 0; i < LED_BUFFER_SIZE; i++) {
        ledBuffer[i] = 0;
    }
}

// Update LED states based on status registers
//
// Priority is deliberately safety-first: a fault is shown even though the
// slot is also, necessarily, not running. The previous ordering tested
// "not running" first, which meant a trip looked identical to an idle slot.
//
void LEDDriver_update(void) {
    static uint32_t tick = 0;

    tick++;

    for (uint16_t ch = 0; ch < NUM_LEDS; ch++) {
        // The status register is the first of a slot's 12 runtime registers.
        uint16_t regIdx = BTS_RT_BASE(ch) + BTS_RT_STATUS;
        uint32_t status = (uint32_t)registers[regIdx];
        uint16_t* ledData = &ledBuffer[ch * 3]; // GRB order
        const uint16_t* color = 0;

        if (status & (1UL << BTS_STATUS_SLOT_DISABLED)) {
            // Masked off by the ENABLE strap - never going to run.
            color = colorRed;
        } else if (status & (1UL << BTS_STATUS_OVERCURRENT_TRIP)) {
            color = ((tick % LED_TRIP_PERIOD) < LED_TRIP_ON) ? colorRed : 0;
        } else if (status & (1UL << BTS_STATUS_REVERSE_POLARITY)) {
            color = ((tick % LED_REVERSE_PERIOD) < LED_REVERSE_ON) ? colorRed : 0;
        } else if (status & (1UL << BTS_STATUS_GROUP_DISCONNECT)) {
            color = ((tick % LED_DISCONNECT_PERIOD) < LED_DISCONNECT_ON) ? colorRed : 0;
        } else if (status & (1UL << BTS_STATUS_CALIBRATING)) {
            //
            // Ranked below the fault states on purpose: a slot that trips
            // during calibration must still read as tripped.
            //
            color = ((tick % LED_CAL_PERIOD) < LED_CAL_ON) ? colorWhite : 0;
        } else if (status & (1UL << BTS_STATUS_PAUSED)) {
            //
            // Ranked below the faults and above running, like the
            // calibration flash. A watchdog or restore pause flashes red -
            // the link died or the unit reset - a deliberate one blue.
            //
            const uint16_t* pauseColor =
                (status & ((1UL << BTS_STATUS_WD_TRIPPED) |
                           (1UL << BTS_STATUS_RESTORED))) ? colorRed : colorBlue;
            color = ((tick % LED_PAUSE_PERIOD) < LED_PAUSE_ON) ? pauseColor : 0;
        } else if (status & ((1UL << BTS_STATUS_BALANCING) |
                             (1UL << BTS_STATUS_SOFT_START))) {
            //
            // Driving the rail, or starting into a freshly seated cell.
            // Ranked below every fault - a slot that trips while balancing
            // must still read as tripped - and above the direction states,
            // which it precedes.
            //
            color = ((tick % LED_BALANCE_PERIOD) < LED_BALANCE_ON)
                        ? colorYellow : 0;
        } else if (status & (1UL << BTS_STATUS_READY)) {
            //
            // Rails matched: it is safe to seat a cell. Flashing, because
            // solid green is idle.
            //
            color = ((tick % LED_READY_PERIOD) < LED_READY_ON)
                        ? colorGreen : 0;
        } else if (status & ((1UL << BTS_STATUS_CHARGING) |
                             (1UL << BTS_STATUS_DISCHARGING))) {
            if (status & (1UL << BTS_STATUS_RUNNING)) {
                color = colorBlue;
            } else {
                color = colorGreen;
            }
        } else if (status & (1UL << BTS_STATUS_FINISHED)) {
            color = colorWhite;
        } else {
            // Idle, or simply not under control.
            color = colorGreen;
        }

        if (color) {
            ledData[0] = color[0]; // G
            ledData[1] = color[1]; // R
            ledData[2] = color[2]; // B
        } else {
            ledData[0] = 0;
            ledData[1] = 0;
            ledData[2] = 0;
        }
    }
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

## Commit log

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2020-12-16 Adding TIDA-010086 project
    Imported Ti TIDA-010086 project
    Imported ControlCARD projects
    Extended TIDA for 1khz CC loop bandwidth
    Modified for RA ControlCard connector
    Modified for F28379D Pinout
    Added NTC temp sensing
    Added SAR ADC OpAmps
    Added Vbias to Current for HW Compatators (OCP+UCP Functions)
    Added ADC clock buffers
    Added 12V rail monitoring
    Added Reverse Polarity protection (with indicator)
    Added ESP32/CC3220 WiFi modules
    Added Canbus, Serial and I2c breakout
    [29197.PcbLib, F2837x_180controlCARD_R1_3_BOM_02Oct2015.xlsx, F2837x_180controlCARD_R1_3_SCH_PADS.sch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]
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2026-09-17 Fix dual-core IPC data flow and get both CPU1/CPU2 configurations building
    Both cpu1 and cpu2 now build and link with 0 errors and 0 code warnings.
    Previously cpu1 failed to link with 5 undefined symbols and cpu2 could not
    compile at all.
    Enforce single-writer discipline on the message RAMs
    ----------------------------------------------------
    The F2837xD message RAMs are single-writer: CPU2TOCPU1RAM is writable only
    by CPU2, CPU1TOCPU2RAM only by CPU1. registers[] lives in CPU2's RAM, so
    CPU1 must never write it - but it did, in four places (status, cell V/I,
    input voltage, unit state).
    CPU1 now publishes measurements and status through a new cpu1Status block
    in its own RAM, and CPU2 mirro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
    [bts.c, bts.h, bts_cpu1.c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]
2026-09-17 Fix dual-core pin/peripheral handover, CMPSS trip routing, and SCI console
    The trip system, the CPU2 peripherals and the console were all
    non-functional on hardware. The underlying causes were separate but
    overlapping, so they are fixed together.
    Clocking:
    DEVICE_SYSCLK_FREQ was computed with a x17 multiplier while
    DEVICE_SETCLOCK_CFG programs SYSPLLMULT=16. Every derived rate was
    6.25% high, putting the SCI console 5.65% off 115200 - outside UART
    tolerance - and skewing the I2C and CAN bit rates by the same factor.
    Dual-core handover (bts_cpu1.c, bts_hal.c):
    GPIO mux, pad and qualification registers are writable only from CPU1,
    so GPIO_setPinConfig() calls in com_cpu2.c were s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
    [bts_cpu1.c, bts_hal.c, bts_hal.h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]
2026-09-18 Fixed i2cb startup, F-RAM no reads and ADS1119 responds. ADS1119 still not configured correctly.
    [bts.c, bts.h, bts_cpu1.c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]
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2026-09-18 Make ADS1119 acquisition non-blocking and fix cell temperature readings
    The DRDY interrupts ran entire I2C transactions inline - an RDATA frame
    plus a reconfiguration write, with spin-waits throughout. That starved
    everything else on CPU2: the AT console dropped characters and the I2CA
    slave could not answer the host while a conversion was being collected.
    Replace that with a state machine driven from the idle loop. A DRDY edge
    now only records that a result is waiting; BTS_serviceADS1119() advances
    one short, non-blocking step per call, so the bus is driven continuously
    while the interrupts stay trivially short. Calibration saves are deferred
    the same way - saveAllCalibration() used to run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
    [com_cpu2.c]
2026-09-18 Add rotary encoder input and fix ST7789 colour byte order
    Adds a rotary encoder with push switch as the unit's local control, and
    fixes two display bugs found while bringing it up.
    Encoder (GPIO15/13 quadrature, GPIO2 switch):
    Decoded by PCNT rather than GPIO interrupts. PCNT has a hardware glitch
    filter, and mechanical encoders bounce badly enough that an ISR decoder
    miscounts on nearly every detent. Both channels are counted in full
    quadrature, which also rejects the single-channel bounce that makes cheap
    encoders jump backwards. Events are delivered on a queue, so nothing runs
    in an ISR.
    PCNT calls gpio_input_enable() on its channel pins but never touches the
    pull resistors, so A and B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
    [display.c, input.c, main.c]
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2026-09-21 Fixed interrupt group ack for ADS131M08 and Vin scalling of C2k 3.0Vref and added LED heartbeat
    [bts.h, bts_cpu1.c, bts_hal.c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]
2026-09-21 Fixed trip zones all tripping EPWM1
    [bts_hal.c]
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2026-09-22 Updated FLASH Layout to correct booting of CPU1 and CPU2 and resolved CLK startup in debug
    [bts_cpu1.c, bts_hal.c, bts_hal.h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]
2026-09-22 Fix ADS1119 AIN-to-slot mapping; thermistors are wired in reverse
    The thermistor inputs are wired in reverse on both ADS1119s: the highest
    AIN carries the lowest slot. U7 (0x40) AIN3..AIN0 are slots 1..4 and
    U9 (0x41) AIN3..AIN0 are slots 5..8.
    ads1119Service() published the raw AIN index as the slot, so every cell
    temperature landed on the wrong slot - a hot cell on slot 1 was reported
    as slot 4. Nothing looked wrong because all eight channels normally sit
    at the same ambient reading.
    Verified on hardware: a thermistor taped to the ESP32 reads ~33 C against
    ~18.9 for the unconnected inputs. Before this change it appeared on
    AT+Ch3_CellTemp?; after it appears on AT+Ch0_CellTemp?, i.e. slot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
    [bts_hal.c, com_cpu2.c, registers.h]
2026-09-22 Serialise I2CB between the F-RAM and the ADS1119 state machine
    I2CB carries the FM24V10 F-RAM at 0x50 and the two ADS1119 converters at
    0x40/0x41, driven from the same idle loop by two incompatible styles of
    access: the converters use a non-blocking state machine that leaves a
    transfer in flight across service calls, while the F-RAM drives a whole
    frame to completion inside one call.
    Nothing kept them apart. BTS_serviceDeferredWork() started a blocking
    F-RAM frame while the state machine was part way through its own, so the
    two were interleaved on the wire: both were corrupted, the controller was
    left holding SCL, and the recovery that followed could not free it either.
    Measured before this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
    [com_cpu2.c]
2026-09-23 Refresh the register-map documentation against the v2.1 map
    api-specification.md, supervision-and-state-design.md and the root README
    still described the v1 map: 314/315 registers, settings stride 24, unit base
    1152, top address 1256. The v2 reorder and the v2.1 settings compression left
    all of that wrong, and a host following it would address the wrong registers.
    Corrected to the map as built: 267 registers, settings stride 18, unit base
    960, top address 1064. eWatchdogRemaining_s is at 1028, not 1220, and the
    mirror now declares it - so the "one register short of the top address"
    defect noted in earlier revisions no longer applies.
    calibration-design.md keeps its mathematics, opcodes, st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
2026-09-23 Filter the internal ADC on CLA1 for telemetry
    The internal ADC converts at 6.645 kSPS, but telemetry only ever saw 1.2 ms
    of every 100 ms: adcCellVoltageISR pushes each sample into an 8-deep ring and
    BTS_monitor_Iout_Vout means that ring at 10 Hz in C1(). 98.8% of the samples
    were discarded, and whatever ripple happened to fall inside the window aliased
    straight through - a 44-count spread on channel 4's current, about 259 mA of
    apparent noise on a steady load.
    CLA1 task 1 now runs on EVERY conversion and folds each sample into a
    single-pole IIR, y += alpha*(x - y), alpha 0.018912 for a 20 Hz corner. Same
    load measured after the change: about 2 counts, roughly 11 mA. Around a 20x
    reduction,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
    [bts_cpu1.c, bts_hal.c, bts_user_settings.h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]
2026-09-23 Document the ADC data flows and the CLA1 allocation
    data-flow.md gains the measurement path as it actually runs. The silicon-to-
    phone diagram now shows the ADC sweep fanning out to both the C28x ISR and
    CLA1 task 1, with the reverse-polarity and group-supervision path drawn
    separately so the telemetry-only boundary is visible rather than implied. A
    new section works through why the filter exists: the 8-deep ring is 1.2 ms of
    history meaned once per 100 ms, so 98.8% of samples were being discarded and
    ripple inside that window aliased through. Includes the bench evidence, 44
    counts of raw spread against about 2 filtered, and the fail-back behaviour
    when BTS_claRunCount stops advancing.
    The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
2026-09-23 ToDo 01: pack the whole slot into the CAN telemetry frame
    The per-slot telemetry frame carried raw floats and ran out of room. It
    packed all four bytes of the voltage and then had two bytes left for the
    current, so it transmitted the low 16-bit word of that float and stopped -
    the half without the sign or the exponent, which made the current
    unreconstructable rather than merely coarse. mAh and mWh did not fit at all,
    though canData had been carrying both for some time.
    Fixed-point removes the failure mode rather than narrowing it. Nothing on the
    wire is a float now, so nothing can be truncated:
    Byte 0 slot index (bits 0-3), run state (bits 4-7)
    Byte 1-2 voltage, signed 16-bit milli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
    [bts_cpu1.c, com_cpu2.c, registers.h]
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2026-09-24 ToDo 02: enable the hardware over-current trips, grouped by the MODE strap
    The CMPSS comparators were configured, routed nowhere useful, and masked off
    on every slot. They now reach the ePWM trip zones and latch the PWM low within
    a switching cycle, grouped so that an over-current on any member of a group
    stops every member of it.
    Two defects turned up on the way in, and both mattered more than the feature.
    THE THRESHOLD MATHS WAS BUILT ON THE WRONG ZERO. bts_user_settings.h assumed
    0 A sat at DAC mid-scale. The sense chain - as the same file already documented
    at BTS_F28I_GAIN_DEFAULT, measured on hardware - puts 0 A at the
    instrumentation amplifier's 1.25 V common mode. Against the measu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
    [bts.c, bts.h, bts_cpu1.c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]
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2026-09-30 ToDo 04: move the LED timer off Timer 0 and switch the control law to CCCV
    THE LEDS WERE DEAD IN EVERY PRODUCTION BUILD. initADS1119() reprograms CPU2's
    Timer 0 to a free-running 0xFFFFFFFF period with its interrupt DISABLED, and
    main() calls it after LEDDriver_init() - so the WS2812B tick was switched off
    moments after it started, having briefly worked at boot. A frozen LED showing
    "running" for a slot that has since tripped is actively misleading, which is
    what made this worth fixing rather than documenting.
    Moved the LED dwell to CPU Timer 2 rather than guarding the ADS1119 setup: the
    dwell genuinely needs a free-running counter in both build flavours, and
    Timer 2 has no other claimant o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
    [ble_verify.py, bts_cpu1.c, bts_link.c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]
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2026-09-30 Clear the CC/CV status bits on a slot that is not regulating
    Found on hardware: an empty slot 1 published status 0x80 - CONST_CURRENT -
    while running == 0. Every idle slot claimed constant-current regulation, so a
    host would have shown eight stopped slots as "in CC".
    ctrlMode_logic is 0 both for an idle slot and for a slot genuinely running in
    constant current, so testing it alone cannot distinguish them. These bits
    report what the control loop is doing and only mean anything while the loop is
    closed, so both are now gated on slotIsRunning().
    This contradicted what the ToDo 04 documentation already promised - "both read
    false for a stopped slot" - so the code was wrong, not the docs. It co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
    [bts_cpu1.c]
2026-09-30 Add an AT command console to the ESP32, reaching the C2000 over I2C
    The unit's own AT console lives on SCIA, which is contended four ways - the
    console, the WS2812B LED driver, channel 1's GPIO trip on GPIO28, and CPU1's
    SFRA GUI. A production unit gives SCIA to the LEDs, leaving no console at all.
    This puts the same interface on the ESP32 without taking anything back.
    The grammar is the unit's, command for command: AT+<name>? reads,
    AT+<name>=<value> writes, AT+C<n>PAUSE and AT+C<n>RESUME act on a slot, every
    response is CRLF terminated, values render to two decimals, and a bare "AT" is
    ignored exactly as the firmware ignores it. Both short and long register names
    resolve, case sensitively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
    [at_console.c, check_at_parity.py, gen_at_registers.py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]
2026-09-30 SFRA modes select PLANT or CLOSED; neither sweeps the internal ADC
    Mode 6 becomes eModeSfraAds131Plant and mode 7 eModeSfraAds131Closed. Both
    tune the ADS131M08 loop - the two values now select WHAT is measured rather
    than which converter:
    PLANT injects at the duty cycle, loop open, measuring the converter
    itself. This is what a new set of DCL coefficients is derived FROM.
    CLOSED injects at the current setpoint, loop closed, measuring the tuned
    system. This is what CONFIRMS coefficients once installed.
    Both collect the sensed current, so only the injection point moves.
    The internal ADC is no longer swept at all. It is a 12-bit converter feeding a
    telemetry filter, n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
    [bts.h, registers.h]
2026-10-01 ToDo 08: pre-charge balance, so a cell is seated onto a matched rail
    A lithium cell is a stiff source. Dropped onto a flat output capacitor it
    dumps charge through the contacts, and closing the synchronous rectifier onto
    a pre-biased cell drives current backwards through the power stage. The slot
    now drives its rail to match the cell BEFORE contact, so the connection closes
    across near-zero volts, then starts in diode emulation rather than CCM.
    WHAT MADE THE SEQUENCE DECIDABLE. The blocking question in the plan was how to
    distinguish "balanced successfully" from "cell inserted" - both read as
    matching voltages. The user's answer: the output capacitors sit AFTER the
    current sense resistor, s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
    [ble_verify.py, bts.c, bts.h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]
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2026-10-01 Fix the DCL coefficients initialising to zero - both loops were dead
    Found on the live unit while deploying: AT+CVB0? returned 0.00 where the
    shipped default is 8.0377, and BTS_ctrl_cv[0].b0 read 0.0 on the target. Both
    the CC and CV biquads had every coefficient at zero on every slot. A biquad
    with all-zero coefficients produces a constant zero output, so neither control
    loop could regulate anything. This was true of every build since the slot
    tuning registers were added in ToDo 06.
    Two independent faults, each sufficient on its own.
    FIRST: CPU1 cannot write registers[]. It is placed in CPU2TOCPU1RAM, which the
    F2837xD makes writable only by CPU2 - registers.c says so in its own header,
    "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
    [bts.c, bts_cpu1.c, com_cpu2.c]
2026-10-02 Fix SCIA being stranded by an unstrapped MODE, which left the LEDs dark
    The WS2812B string was connected and showing nothing. Pin muxing and GPIO
    ownership were both correct, which is what made this hard to see: GPAMUX2 had
    GPIO29 at mux=1/gmux=0 (SCITXDA) and GPACSEL4 had it assigned to CPU2. The
    fault was one level up - every SCIA register read back 0x0000, meaning the
    module was never configured at all.
    CPU1 keeps SCIA for the SFRA GUI when btsSfraActive is set, and only hands it
    to CPU2 otherwise. btsSfraActive was latched from the MODE strap alone. The
    straps on this unit are open, the pull-ups make them read 0b111, truth_table[7]
    decodes that to mode 7 - which ToDo 07 defined as eMode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
    [bts_cpu1.c, bts_user_settings.h]
2026-10-02 Move the WS2812B transfer out of the timer ISR - it was starving CPU2
    Two symptoms, one cause. The ESP32's display cycled between "WAITING FOR BTS"
    and live data, and CPU2's heartbeat LED - meant to blink on a 5 s period when
    idle - stretched to roughly a minute, about 10x slow.
    ledTimerISR did the whole refresh inline: 24 bytes clocked out at 800 kbaud is
    300 us, plus a 60 us busy-wait for the WS2812B reset pulse. Around 360 us per
    call, 80 times a second.
    The duration alone is only ~3% of the core. What made it fatal is that
    ledTimerISR is the one ISR on CPU2 not declared HPI, so it ran with interrupts
    disabled for that entire window. CPU2's I2C target ISR fires on every received
    byte (S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
    [at_console.c, com_cpu2.c, led_driver.c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]
2026-10-02 Move the WS2812B drive to the ESP32 - a UART could never have lit it
    The C2000 LED driver has never lit a pixel, and could not have. It clocked
    raw colour bytes out of SCIA at 800 kbaud, but a WS2812B decodes pulse
    widths - 400 ns high is a 0, 800 ns high is a 1, in a 1250 ns slot - and a
    UART cannot produce them: it forces a LOW start bit before every byte and
    holds each data bit for a whole bit time. The strip saw framing noise and
    latched nothing. Every earlier fix in this area (the ISR starvation, the
    SCIA stranding) was real and worth keeping, but none of them addressed
    this, which is why the string stayed dark through all of them.
    Driving it properly needs a peripheral that emits a fr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
    [bts_user_settings.h, led_strip.c, main.c]
2026-10-02 Fix the cell-voltage scale, and three defects found chasing a startup trip
    The cell voltage read 1.45 V for a 3.492 V cell. F28V_Gain was 1.0, so the
    ~2.412:1 divider on the on-chip sense was never undone and every host saw
    the voltage AT THE PIN while the register was named for the cell. Not
    cosmetic: a discharge cut-off is compared against this number, so at a 2.5 V
    floor a full cell read as already empty.
    validateCalibration() accepted 0.5..2.0, which could not express 2.412 at
    all while admitting the wrong default. Band widened to 2.0..3.0 and both
    defaults set to the measured 2.4121. A stored 1.0 is now rejected and falls
    through to applyDefaultCalibration(), so existing F-RAM records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
    [bts.h, bts_cpu1.c, bts_hal.c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]
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2026-10-02 Bring the docs, the tools and every map comment to v2.1
    The 2026-09-22 settings compression moved every settings and unit address,
    and the slot tuning block was appended above the unit block afterwards. The
    headers were updated; most of what describes them was not.
    One functional defect, in tools/calibrate.py. REG_CAL_BASE and
    REG_CAL_STRIDE were still 384+44 and 96, so every slot's before/after gain
    table read another slot's calibration block. It failed silently: the read
    succeeded and returned plausible floats. Now 384+24 (408) and 72, verified
    against registers.h end to end - slot 0 lands on 408, slot 7 on 912, and
    slot 7's twelfth register on 956, exactly eCh7_VoutOffset_V.
    tools/ble_v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
    [ble_verify.py, bts_link.c, bts_regs.h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]
2026-10-08 Standalone flash startup works: both cores boot from flash with no debugger
    The unit now powers up from flash on its own. Verified with SW1 OFF (boot to
    flash) and the XDS100 disconnected: CPU1 boots, starts CPU2, both reach their
    main loops, and the ESP32 reads live values over I2C.
    BOOT
    _STANDALONE is now defined beside _FLASH in cpu1, cpu2 and cpu1_sfra, so
    CPU1 starts CPU2 itself. Both images already had code_start at 0x080000.
    CPU1 no longer hangs waiting for CPU2. driverlib's Device_bootCPU2() spins
    with no timeout until CPU2's boot ROM reports ready, so a CPU2 that never
    got there stopped CPU1 before its control tasks, supervision or trip
    arming ran. tryBootCpu2() makes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
    [bts_cpu1.c, com_cpu2.c]
2026-10-08 Fix the ESP32 crashing whenever the BTS stopped answering
    The proxy panicked with a LoadProhibited inside ESP-IDF v6.1's I2C driver,
    s_i2c_write_command(), reading 0xaeaf2135 - an operation whose data pointer
    was 0xaeae49f1 and whose byte offset was 55108. Decoded from the panic dump in
    the COM6 serial log against build/bts_btle_proxy.elf (SHA 36f7154f1). The
    call chain was bts_poll_task -> poll_one_channel -> bus_read_block.
    That operation was not ours. i2c_master_probe() points the bus's operation
    list at an array on its own stack and never clears it, and unlike the device
    transfer paths it does not reset the controller FSM after a NACK or timeout.
    A late interrupt from a failed probe the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
    [bts_link.c]
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2026-10-08 Move the Home Assistant integration to its own repo, as a submodule
    Hardware/source/lion-lvrt-integration is now the git submodule
    https://github.com/ArakniD/ha-lion-irvt (branch main), at the same path,
    so it can be installed through HACS without the firmware.
    History was carried over with git subtree split: all five commits that
    touched this directory are in the new repo with their original messages
    and dates, merged onto its initial LICENSE commit.
    Same path on purpose. The integration's layout tests read the C2000
    registers.h and the ESP32 ble_proto.h / bts_regs.h from the parent
    directory, and every client bug on record here was a silent layout drift
    those tests exist to catch. Run fr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
    [bts_regs.h]
2026-10-08 ESP32: fixes from the first bench run of OTA and WiFi setup
    First run on a fresh ESP32 (no BTS attached), flashed over USB, then
    updated over WiFi twice. What the bench turned up:
    - An update key longer than 64 characters was silently cut to 64 and
    saved, leaving the operator holding a key the unit did not have. The
    JSON parser truncates without saying so; the handler now reads into a
    double-width buffer so ota_key_set() sees the real length and refuses.
    - With a saved network absent, a flat 30 s retry left the setup page
    unreachable for ~20 s of every 35: each scan takes the one radio off the
    AP's channel and the client drops and rejoins. Retries now back off to
    5 minutes while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
    [ble_verify.py]
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2026-10-09 C2000: bind each slot's hardware trip to its own comparator; over-current clears; GPIO trips off
    Slot n is not watched by CMPSSn. Each comparator's input pins are fixed by
    the device, and this board routes each slot's sense nets for layout, so the
    comparator on slot n's current pin is CMPSS 1, 3, 2, 4, 7, 6, 8, 5 for slots
    1-8 (schematic XTIDA-010086E3 sheet 13, datasheet SPRS880 Table 4-1). The
    routing assumed CMPSSn, so in the ungrouped and pair modes slots 2 and 3
    tripped on each other's current and 5, 7 and 8 in a ring. Quads and the
    octet were unaffected.
    The binding is now BTS_TRP_CMPSS_CH1..8, which fails the build unless it is
    one-to-one. btsSlotCmpss[] applies it, the mux tables ar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
    [bts_cpu1.c, bts_hal.c, bts_link.c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]
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2026-10-09 CPU2: I2CB frames wait for STP to clear, not just the bus; MODE/ENABLE tables
    Slot temperatures stalled. About 1.5 % of I2CB frames to the ADS1119s
    timed out, all the same way: start and address on the wire, then nothing,
    with I2CSTR SCD|XSMT|NACKSNT and I2CMDR still holding the frame's own start
    word (0x6220). The module drops BB when a stop reaches the wire but clears
    STP only after SCD, a few cycles later. Every frame start waited for !BB
    alone, so a start written into that gap was lost. The TRM says to wait for
    STP (SPRUHM8K, I2CMDR.STP), as TI's i2c_ex2_eeprom does.
    Each loss counted as a converter failure and was retried, so readings came
    late and in bursts and a converter could go qu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
    [com_cpu2.c]
2026-10-10 C2000: ADS131M08 CLKIN in spec, filtered loop inputs, smoothed Vin; data-flow docs
    - ADS131M08 CLKIN 9.0 -> 8.18 MHz: the EPWM11/12 period now rounds instead
    of truncating (TBPRD 10), so fDATA is 31.96 kSPS. The switching frequency
    is fixed at 99.67 kHz instead of being derived from the ADC clock.
    - Every DRDY, BTS_conditionCtrlInputs() feeds the CC loop a 4-sample rolling
    mean (-3 dB 3.54 kHz) and the CV loop a 100 Hz IIR. The trip and the
    direction guard keep the raw sample. Loop rate and DCL coefficients
    unchanged.
    - Vin: 16x oversampled against the A0 reference, then an IIR with alpha
    0.25. Measured span 40 mV over 30 s, down from about +/-0.5 V.
    - Docs: ADS131M08 and Vin dat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
    [bts.h, bts_cpu1.c, bts_hal.c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]
